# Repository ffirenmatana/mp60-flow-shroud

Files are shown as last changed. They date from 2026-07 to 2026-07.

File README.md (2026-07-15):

# MP60 low-profile 90° fan shroud (bottom-mounted VorTech)

A drop-in replacement for the EcoTech VorTech **MP60 wet-side cage** for
**through-the-bottom mounting** in a peninsula reef tank. Single 3D-printed
part: the stock bayonet mount and perforated intake barrel, plus a swept 90°
elbow that turns the vertical discharge into a wide, floor-angled ~90°-arc
sheet of flow aimed down the tank — a hideable gyre substitute for the open
end of a peninsula.

Total height **179 mm off the glass** (parametric). Geometry chosen by CFD:
a local optimization loop (lattice-Boltzmann sims + an LLM proposer) ran
dozens of 2D flow simulations, including full 1.8 m tank-scale runs with
rockwork, to pick every dimension. Details below.

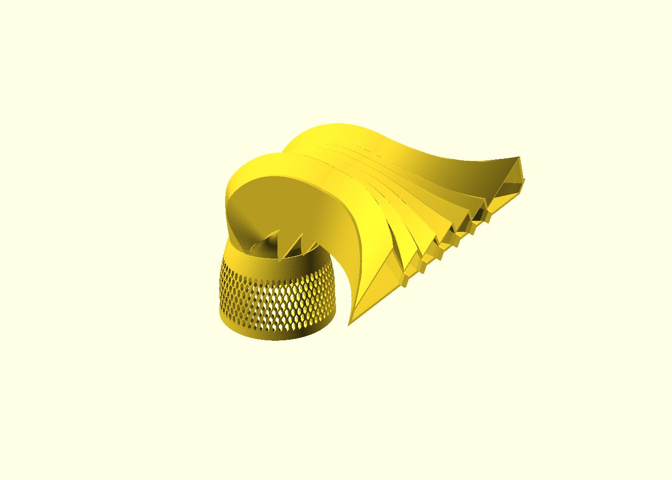
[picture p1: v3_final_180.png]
final part


## Design highlights (what the sims taught us)

| finding | detail |
|---|---|
| swept vaneless elbow | K ≈ 0.19 — turning vanes made it *worse* (0.61), mitered/louvered corners much worse (1.3–2.4). At this scale vane friction+wakes beat separation savings. |
| pump keeps ~97% flow | propeller-stall derating model: 5.35 of 5.52 L/s at 70% drive |
| fan needs vanes | without cambered splitter vanes the widening fan tunnels straight (spread σ20 mm); with 6 vanes it fills the full arc (σ57 mm) |
| 15° floor tilt | sweeps detritus off the bare bottom; 25° drives the sheet into the rockwork and dies |
| launch height rule | **the exit must clear the rock directly in front of it by 20–40 mm** — a below-crest exit dead-ends in a trapped vortex no matter the duct shape. This build: exit at 118 mm → keep foreground rock under ~93 mm |
| gothic-ridge roof | chevron cross-sections keep every interior surface ≥45°: single print, rim-down, supports only under the fan floor (build-plate) |

Tank-scale result vs a below-crest exit: coral-zone coverage 0 → 4.8%,
rock wrap-over 2.2×, dead zones behind rocks 100% → 73%.

## Files

- `mp60_shroud_v3.stl` — generated locally (325 cm³; 226×256×175 mm, fits Prusa Core One L 300×300×330), see below
- `build_v3.py` — fully parametric generator (numpy lofts + manifold
  booleans). Key knobs at top: `MAX_TOTAL_H_GLASS` (height cap, default
  180), `MAX_BED_XY` (build-plate cap, default 300), `WETSIDE_H`, wall, vanes. Reads `agent/final.json`.
- `cfd/lbm.py` — D2Q9 lattice-Boltzmann + Smagorinsky LES solver:
  elbow slice, fan plan, and closed-tank (with rocks, free surface,
  actuator jet) planes. Mass-balance-validated.
- `agent/` — the local optimization loop: qwen3:14b (Ollama) proposes
  candidates, this machine runs 8 parallel sims/round, tank sims decide
  finals. `agent/log.md` is the full campaign narrative.
- `cage.stl` — the stock cage mesh the part is built on (see attribution)

Earlier revisions (v1 OpenSCAD clamshell, v2 mitered-corner) are not in the
working tree; they live in git history if ever needed.

## Test the fit first (recommended)

Before the ~2-day full print, print the mount coupon — the bottom 22 mm
(bayonet + barrel), ~30 min, and twist it onto the wet side to confirm the
lock seats:

```bash
python3 make_coupon.py            # -> mp60_mount_coupon.stl
python3 make_coupon.py --pump mp40
```

The coupon is a boolean slice of the full part, so its mount geometry is
identical (verified 0.0000 mm vs the cage) — a good coupon fit means a good
part fit. Print it in the same PETG, no supports, no brim needed.

## MP40 variant

`build_v3.py --pump mp40` generates the same architecture scaled to the
MP40 cage (bore Ø56.9, three lugs at 120°, total ≈141 mm above the
glass). You need an MP40 wet-side cage mesh saved as `cage_mp40.stl`
(rim at z=0, axis up — the extractor's rotation applies; check the
license of whichever cage model you use before redistributing).

## Fidelity caveats

2D LES slices at reduced Reynolds number: excellent for *ranking*
geometries and flow topology (every decision here), indicative-only for
absolute velocities. The tank plane is a 2D vertical slice — real 3D
spread will be gentler. Not yet wet-tested; sim-driven design.

## Print & install

Slicer: PrusaSlicer, "Original Prusa Core One L" profile. Black PETG
(carbon black = UV stabiliser), 0.2 mm layers, 4 perimeters (walls are
3.2 mm = solid at 4), 15 % gyroid infill (part is mostly hollow duct).
Nozzle 245 °C, bed 85 °C, chamber passive/low (PETG doesn't want chamber
heat). Cooling fan ~30–40 % (bias to layer strength). Elephant-foot
compensation 0.15 mm (protects the bayonet-lug fit). Brim 5 mm.

Supports: **organic (tree), build-plate only, 45° threshold** — only the
fan underside needs them; the gothic roof self-supports. ~490 g PETG total.

Print the mount coupon first (`make_coupon.py`, ~30 min) to check the
bayonet before the full run.

Install: rinse, soak 24 h in saltwater, bayonet onto the wet side like the
stock cage, clock the fan down-tank before locking (lugs quantize to 120°
— fine-aim with the pump body). Bottom-mount basics: correct spacer for
your glass, catch bracket under the dry side, run 30–40 % for the first
week and listen to the bushing.

## Getting the STL (license-respecting build)

The intake cage geometry is ["Ecotech MP60 Cover" by asadler99 on
Cults3D](https://cults3d.com/en/3d-model/home/ecotech-mp60-cover), free
under the **Cults Private Use license** — which permits printing for
yourself but not redistribution of the mesh or derivatives. So this repo
does **not** contain `cage.stl` or the final shroud STLs; it contains
everything needed to build them locally in under a minute:

```bash
pip install numpy trimesh manifold3d scipy networkx
# download the free 3MF from the Cults link above, then:
python3 extract_cage.py ~/Downloads/EcotechV60Modified.3mf
python3 build_v3.py            # -> mp60_shroud_v3.stl
```

## Attribution & license

- Cage mesh: (c) [asadler99](https://cults3d.com/en/users/asadler99),
  [Cults PU license](https://cults3d.com/en/licenses#cults_pu) — print for
  private use only; not redistributed here. Thanks for a cleanly-modeled
  base part. (Permission to include the derived STLs has been requested
  from the author, July 2026 — if granted, prebuilt STLs will be added.) VorTech and MP60 are EcoTech Marine trademarks; this is an
  unaffiliated hobby project — use at your own risk.
- Code (generator, extractor, CFD solver, optimizer): MIT.

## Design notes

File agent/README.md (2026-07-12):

# Local optimization agent

Self-contained loop that perfects the MP60 shroud geometry using only
local hardware — no cloud tokens.

```
┌────────────────────┐    proposals+analysis   ┌───────────────────┐
│ M4 MacBook Pro     │ <────────────────────── │ M4 mini           │
│ optimizer.py       │                         │ Ollama qwen3:14b  │
│ 8x parallel LBM    │ ──────────────────────> │ 10.10.10.7:11434  │
│ sims per round     │    history JSON         └───────────────────┘
└────────────────────┘
```

## Run / resume / status

```bash
cd ~/Claude/Projects/MP60-flow-shroud/agent
../cfd-env-or-your-python optimizer.py          # runs or resumes
python3 optimizer.py --status                   # peek at state
tail -f log.md                                  # live narrative
```

State lives in `state.json`; kill and rerun anytime, it resumes.
`best.json` always holds the current winner → feed to `build_v3.py`.

## What a round does

1. qwen (mini) reads the scored history, proposes 4 candidates + a
   2-sentence analysis (logged). Fallback: local Gaussian/random proposer.
2. Each candidate → 2 sims on this Mac (elbow slice + fan plan),
   8 processes in parallel, 40k steps each.
3. Composite score = pump-derated exit momentum × arc coverage ×
   uniformity (see optimizer.py docstring for the MP60 stall model).
4. Plateau detection stops early; max 8 rounds.

## Tier B (the decider)

Top 3 aspect/tilt-distinct finalists get a 90k-step closed-tank sim:
1.8 m peninsula with rockwork (scape in front of the outlet, mid
bommie, near-wall structure), specular free surface, jet actuator at
the shroud exit angled down by the candidate's `tilt`.

Scored on: floor_sweep (detritus scouring), rock_wrap (climbing the
scape), lee_dead_frac (dead zones behind rocks), gyre_index +
wall_arrival (peninsula return loop). qwen renders the verdict;
a metric heuristic decides if it can't.

## Knobs

Env: `OPT_MAX_ROUNDS`, `OPT_N_PER_ROUND`, `OPT_SIM_STEPS`,
`OPT_TANK_STEPS`, `LOCAL_LLM_BASE`, `LOCAL_LLM_MODEL`.
Search space + physical constants at the top of optimizer.py.
Rock layout: `rocks` in `cfd/lbm.py::geom_tank` — edit to match the
real scape once it exists.

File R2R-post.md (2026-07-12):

# Reef2Reef draft — post in DIY / Members' 3D printing

**Title:** CFD-designed 3D-printed shroud turns a bottom-mounted MP60 into a
low-profile gyre for my peninsula — sim code + build recipe included

---

I have an acro-dominant peninsula and wanted serious flow at the open end
without hanging a gyre on the view panel. The plan: MP60 through the bottom
glass (bare bottom, dry side in the cabinet above the sump), with a printed
replacement for the wet-side cage that turns the vertical discharge 90° and
fans it into a wide sheet aimed back toward the wall end — hidden inside the
rockwork.

Instead of guessing the duct shape, I ended up going full nerd: a lattice-
Boltzmann CFD solver running locally, driven by an optimization loop (a local
LLM proposes candidate geometries, my machine simulates them — dozens of runs,
including full 1.8 m tank-scale sims with rockwork in them). A few results
that surprised me and might be useful to others:

- **Turning vanes made the elbow worse.** All the HVAC-style vane/louver
  designs lost badly to a plain swept bend (loss coefficient 0.19 vs 0.6–2.4).
  At powerhead scale, vane friction and wakes cost more than the separation
  they prevent.
- **The widening fan absolutely needs vanes though** — without them the flow
  tunnels straight out the middle instead of spreading into the 90° arc.
- **Where the exit sits beats how the duct is shaped.** If the outlet fires
  at rockwork taller than itself, the flow just churns in the gap and dies —
  every geometry, every time. The exit needs to clear the rock directly in
  front of it by a couple of cm. Sheet angled 15° at the floor then sweeps
  the sand and wraps over the scape; 25° just face-plants into the rock.
- The final part is 179 mm tall off the glass, keeps ~97% of the pump's flow
  (per a prop-stall derating model), prints in one piece in PETG with
  supports only under the fan, and bayonets onto the wet side exactly like
  the stock cage (the mount is the stock cage mesh from asadler99's free
  "Ecotech MP60 Cover" on Cults3D — its Private Use license means I can't
  redistribute the mesh, so the repo has a one-command script that rebuilds
  the STL from the 3MF you download from Cults yourself).

Fair warning: this is simulation-driven design, 2D slices with a turbulence
model — great for ranking shapes, not gospel for absolute numbers. It hasn't
been wet-tested yet; printing this week, will report back with PAR-meter…
sorry, flow-meter results and detritus observations.

Everything is on GitHub (the parametric generator, the CFD solver, the
whole optimization log): **https://github.com/ffirenmatana/mp60-flow-shroud**

Photos attached: the part, a cutaway of the internals, and the tank-scale
flow simulation showing the sheet wrapping over the scape.

*Suggested attachments:*
- `v3_final_180.png` (the part)
- `agent/runs/tank_hi_mid.png` (winning tank flow field)
- `agent/runs/tank_sheet_steep.png` (the "trench of doom" failure mode)
- `cfd/S5_swept_0v.png` (elbow flow field)

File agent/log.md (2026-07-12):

# MP60 shroud optimization log

seeded: [{"params": {"bend_r": 52, "duct_h": 45, "fan_len": 70, "exit_w": 185, "area_ratio": 1.19, "n_vanes": 4, "exp": 1.5}, "score": 0.3944, "metrics": {"K_loss": 0.20199999999999999, "Q_lps": 5.34, "v_exit": 1.114, "exit_h": 25.9, "spread": 45.7, "outfrac": 0.388, "plan_uni": 1.017}, "tag": "seed_S5_swept_0v"}]

## round 1  (18:46)
proposer: qwen. Candidates include variants near the historical best (bend_r=55, exit_w=200) and explore extremes like narrow exits (exit_w=120) and high tilt (30°). Prioritizes improving K and spread through parameter diversification.
8 sims in 15.5 min
- r1c0 {"bend_r": 55.0, "duct_h": 48.0, "fan_len": 75.0, "exit_w": 200.0, "area_ratio": 1.2, "n_vanes": 5, "exp": 1.6, "tilt": 10.0} -> score=0.293 {"K_loss": 0.19, "Q_lps": 5.35, "v_exit": 1.107, "exit_h": 24.2, "spread": 42.0, "outfrac": 0.236, "plan_uni": 1.294}
- r1c1 {"bend_r": 60.0, "duct_h": 50.0, "fan_len": 80.0, "exit_w": 260, "area_ratio": 1.4, "n_vanes": 6, "exp": 2.5, "tilt": 20.0} -> score=0.2945 {"K_loss": 0.17844444444444443, "Q_lps": 5.36, "v_exit": 0.951, "exit_h": 21.7, "spread": 62.9, "outfrac": 0.705, "plan_uni": 1.46}
- r1c2 {"bend_r": 45.0, "duct_h": 36, "fan_len": 55, "exit_w": 120, "area_ratio": 1.0, "n_vanes": 2, "exp": 1.2, "tilt": 0} -> score=0.2774 {"K_loss": 0.17, "Q_lps": 5.37, "v_exit": 1.333, "exit_h": 33.6, "spread": 22.1, "outfrac": 0.021, "plan_uni": 0.655}
- r1c3 {"bend_r": 65.0, "duct_h": 55.0, "fan_len": 100.0, "exit_w": 180.0, "area_ratio": 1.45, "n_vanes": 3, "exp": 2.0, "tilt": 15.0} -> score=0.1976 {"K_loss": 0.2555, "Q_lps": 5.3, "v_exit": 0.907, "exit_h": 32.4, "spread": 35.2, "outfrac": 0.144, "plan_uni": 1.212}
best so far: seed_S5_swept_0v score=0.3944

## round 2  (19:04)
proposer: qwen. Explored variants near the top-performing exit_w=185 with adjusted spread and tilt, while testing extreme exit_w=260 (sheet jet) and tilt=35 (floor-targeting) to explore uncharted regions.
8 sims in 15.2 min
- r2c0 {"bend_r": 52.0, "duct_h": 45.0, "fan_len": 70.0, "exit_w": 190.0, "area_ratio": 1.2, "n_vanes": 4, "exp": 1.6, "tilt": 5.0} -> score=0.3565 {"K_loss": 0.22061111111111112, "Q_lps": 5.32, "v_exit": 1.102, "exit_h": 25.4, "spread": 43.5, "outfrac": 0.31, "plan_uni": 1.054}
- r2c1 {"bend_r": 50.0, "duct_h": 44.0, "fan_len": 65.0, "exit_w": 180.0, "area_ratio": 1.15, "n_vanes": 4, "exp": 1.4, "tilt": 0} -> score=0.4189 {"K_loss": 0.146, "Q_lps": 5.39, "v_exit": 1.163, "exit_h": 25.7, "spread": 45.8, "outfrac": 0.457, "plan_uni": 0.993}
- r2c2 {"bend_r": 60.0, "duct_h": 50.0, "fan_len": 80.0, "exit_w": 260, "area_ratio": 1.4, "n_vanes": 6, "exp": 2.5, "tilt": 20.0} -> score=0.2945 {"K_loss": 0.17844444444444443, "Q_lps": 5.36, "v_exit": 0.951, "exit_h": 21.7, "spread": 62.9, "outfrac": 0.705, "plan_uni": 1.46}
- r2c3 {"bend_r": 44, "duct_h": 36, "fan_len": 55, "exit_w": 120, "area_ratio": 1.0, "n_vanes": 2, "exp": 1.2, "tilt": 35} -> score=0.2716 {"K_loss": 0.2361111111111111, "Q_lps": 5.31, "v_exit": 1.319, "exit_h": 33.6, "spread": 22.1, "outfrac": 0.021, "plan_uni": 0.655}
best so far: r2c1 score=0.4189

## round 3  (19:22)
proposer: qwen. The best historical candidate (score 0.4189) is near the lower bend_r/duct_h range with moderate exit_w. Exploration candidates test higher exit_w (gyre-like sheet), increased tilt (detritus sweeping), and extreme area_ratio/n_vanes combinations. The fourth candidate probes unexplored low-bend_r/duct_h territory with balanced parameters.
8 sims in 14.1 min
- r3c0 {"bend_r": 50.0, "duct_h": 44.0, "fan_len": 65.0, "exit_w": 180.0, "area_ratio": 1.15, "n_vanes": 4, "exp": 1.4, "tilt": 0} -> score=0.4189 {"K_loss": 0.146, "Q_lps": 5.39, "v_exit": 1.163, "exit_h": 25.7, "spread": 45.8, "outfrac": 0.457, "plan_uni": 0.993}
- r3c1 {"bend_r": 55.0, "duct_h": 48.0, "fan_len": 75.0, "exit_w": 220.0, "area_ratio": 1.3, "n_vanes": 5, "exp": 1.8, "tilt": 15.0} -> score=0.2433 {"K_loss": 0.1995, "Q_lps": 5.34, "v_exit": 1.02, "exit_h": 23.8, "spread": 42.1, "outfrac": 0.196, "plan_uni": 1.414}
- r3c2 {"bend_r": 65.0, "duct_h": 55.0, "fan_len": 100.0, "exit_w": 150.0, "area_ratio": 1.45, "n_vanes": 3, "exp": 2.2, "tilt": 25.0} -> score=0.1854 {"K_loss": 0.2798333333333333, "Q_lps": 5.28, "v_exit": 0.904, "exit_h": 38.9, "spread": 28.8, "outfrac": 0.075, "plan_uni": 0.924}
- r3c3 {"bend_r": 48.0, "duct_h": 40.0, "fan_len": 80.0, "exit_w": 200.0, "area_ratio": 1.25, "n_vanes": 6, "exp": 2.0, "tilt": 10.0} -> score=0.348 {"K_loss": 0.2677777777777778, "Q_lps": 5.29, "v_exit": 1.05, "exit_h": 25.2, "spread": 52.8, "outfrac": 0.501, "plan_uni": 1.189}
best so far: r2c1 score=0.4189

## round 4  (19:37)
proposer: qwen. Top candidates cluster near the best historical score (0.4189) with slight parameter adjustments. Unexplored regions include low-exit_w (130) and high-tilt (30), testing detritus-sweeping potential. Area_ratio and exp variations aim to balance jet coherence (exp=1.3-2.4) with flow spread (spread=22-63).
8 sims in 15.4 min
- r4c0 {"bend_r": 52.0, "duct_h": 46.0, "fan_len": 68.0, "exit_w": 185.0, "area_ratio": 1.18, "n_vanes": 4, "exp": 1.5, "tilt": 2.0} -> score=0.3508 {"K_loss": 0.16355555555555557, "Q_lps": 5.37, "v_exit": 1.131, "exit_h": 25.7, "spread": 39.9, "outfrac": 0.296, "plan_uni": 1.03}
- r4c1 {"bend_r": 58.0, "duct_h": 48.0, "fan_len": 72.0, "exit_w": 190.0, "area_ratio": 1.22, "n_vanes": 5, "exp": 1.6, "tilt": 10.0} -> score=0.2413 {"K_loss": 0.1811111111111111, "Q_lps": 5.36, "v_exit": 1.091, "exit_h": 25.9, "spread": 37.4, "outfrac": 0.142, "plan_uni": 1.238}
- r4c2 {"bend_r": 46.0, "duct_h": 38.0, "fan_len": 60.0, "exit_w": 130.0, "area_ratio": 1.05, "n_vanes": 3, "exp": 1.3, "tilt": 30.0} -> score=0.2484 {"K_loss": 0.2293333333333333, "Q_lps": 5.32, "v_exit": 1.258, "exit_h": 32.5, "spread": 23.3, "outfrac": 0.025, "plan_uni": 0.791}
- r4c3 {"bend_r": 62.0, "duct_h": 52.0, "fan_len": 90.0, "exit_w": 250.0, "area_ratio": 1.4, "n_vanes": 6, "exp": 2.4, "tilt": 25.0} -> score=0.3017 {"K_loss": 0.1878333333333333, "Q_lps": 5.35, "v_exit": 0.949, "exit_h": 22.5, "spread": 56.6, "outfrac": 0.622, "plan_uni": 1.368}
best so far: r2c1 score=0.4189
plateau -> stopping tier A early

## tier B: tank-scale gyre sims
- tank_sheet_shallow: r2c1 exit 180.0x26mm v_exit=1.163m/s
- tank_sheet_steep: r4c3 exit 250.0x23mm v_exit=0.949m/s
- tank_diffuse_shallow: r1c2 exit 120x34mm v_exit=1.333m/s
- tank_sheet_shallow -> {"coral_mean_u": 0.0012, "coral_frac_gt_10pct": 0.0, "coral_frac_gt_25pct": 0.0, "wall_arrival_u": 0.0, "gyre_index": 0.0157, "floor_sweep_u": 0.0485, "rock_wrap_u": 0.0691, "lee_dead_frac": 1.0, "tank_mean_u": 0.0946, "name": "tank_sheet_shallow"}
- tank_sheet_steep -> {"coral_mean_u": 0.0026, "coral_frac_gt_10pct": 0.0, "coral_frac_gt_25pct": 0.0, "wall_arrival_u": 0.0001, "gyre_index": 0.0071, "floor_sweep_u": 0.071, "rock_wrap_u": 0.0719, "lee_dead_frac": 1.0, "tank_mean_u": 0.0782, "name": "tank_sheet_steep"}
- tank_diffuse_shallow -> {"coral_mean_u": 0.0052, "coral_frac_gt_10pct": 0.0, "coral_frac_gt_25pct": 0.0, "wall_arrival_u": 0.0001, "gyre_index": -0.0014, "floor_sweep_u": 0.0363, "rock_wrap_u": 0.0984, "lee_dead_frac": 0.995, "tank_mean_u": 0.1117, "name": "tank_diffuse_shallow"}

## VERDICT: {"winner": "sheet_steep", "why": "sheet_steep has the highest floor_sweep_u (0.071), meeting the first goal. While its rock_wrap_u (0.0719) is moderate and lee_dead_frac (1.0) is high, it's the best among options for the first priority. Gyre_index and wall_arrival_u are lower than sheet_shallow, but secondary goals are less critical."}

DONE. best.json written -- feed to build_v3.py

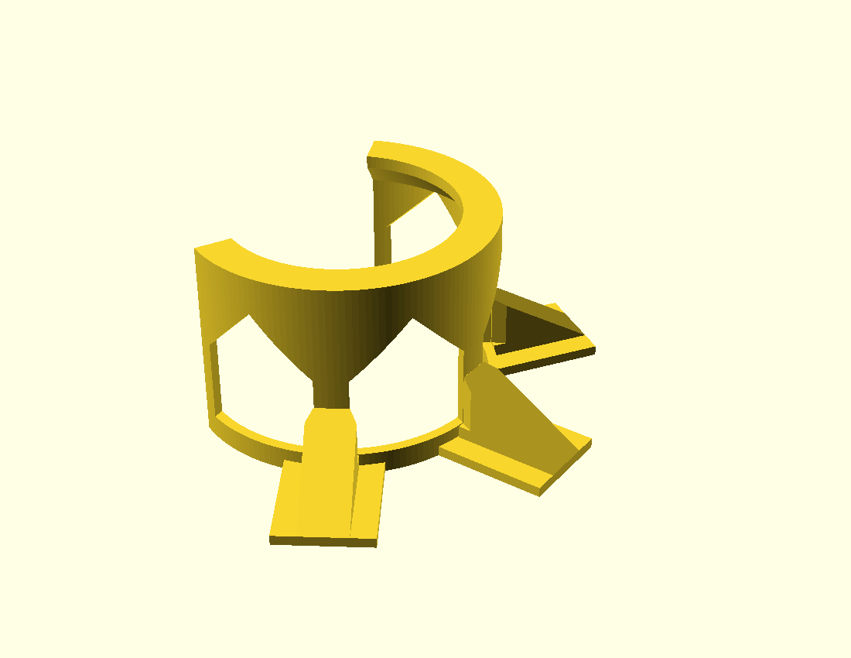
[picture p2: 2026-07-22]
bracket_view1.png

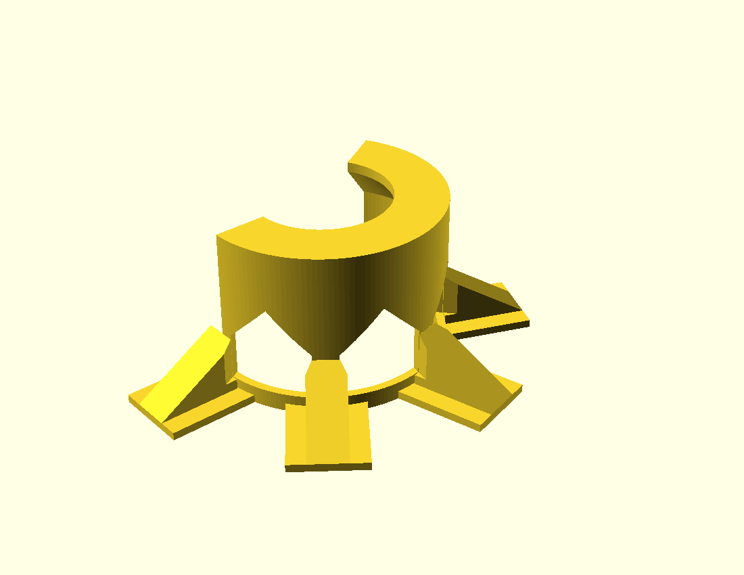
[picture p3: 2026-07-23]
bracket_v3.png

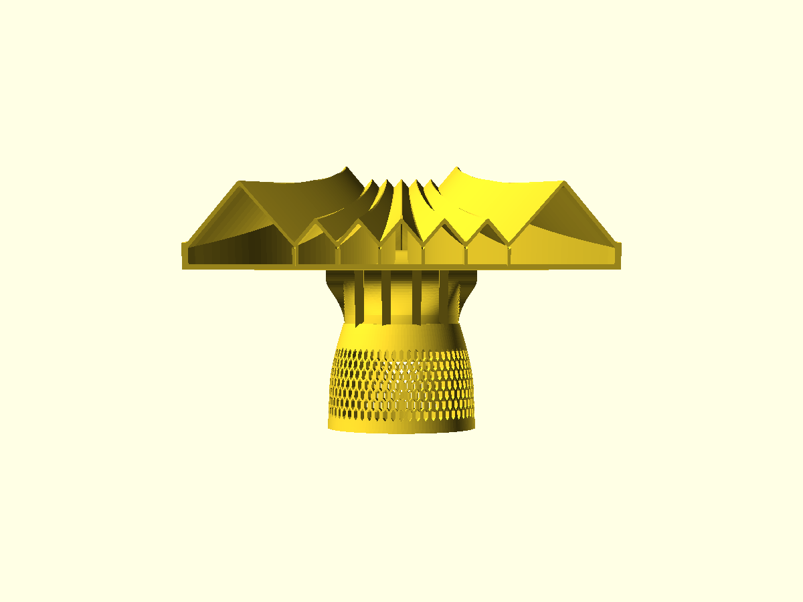
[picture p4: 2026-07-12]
v3_final2.png

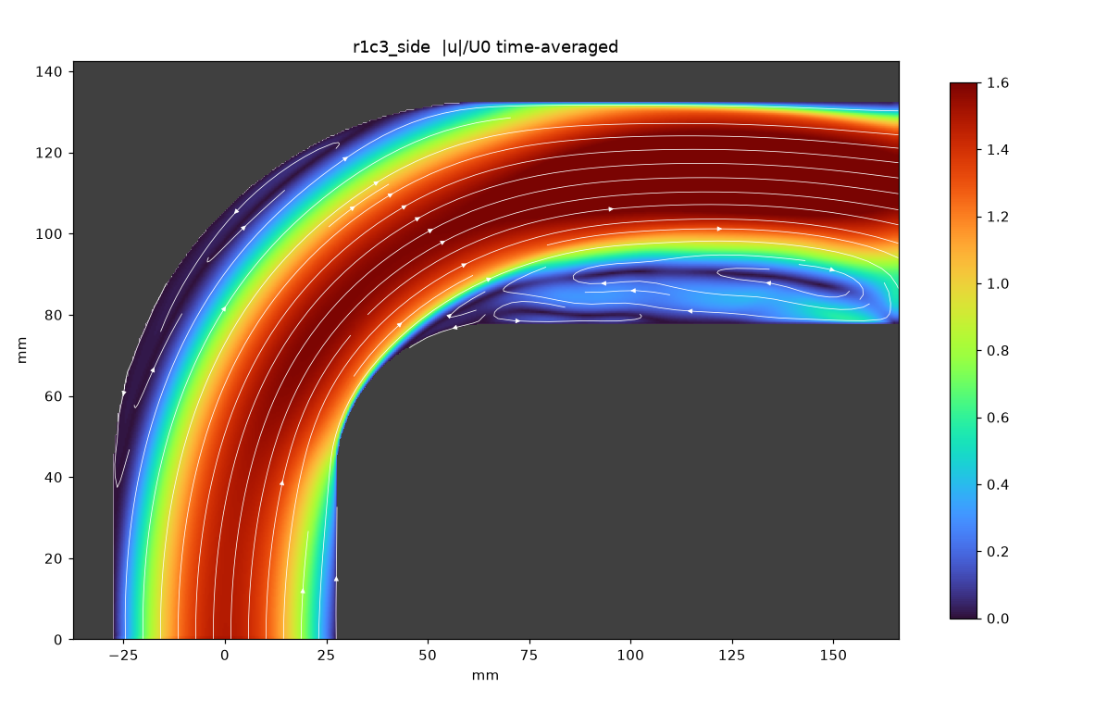
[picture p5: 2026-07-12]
agent/runs/r1c3_side.png

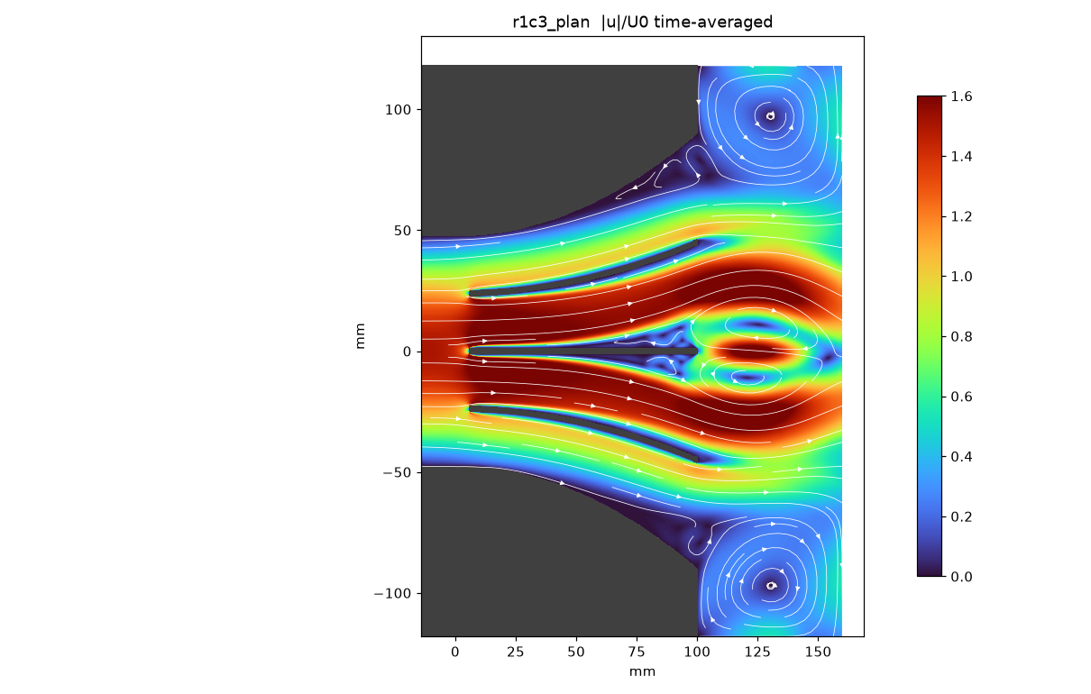
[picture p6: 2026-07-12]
agent/runs/r1c3_plan.png

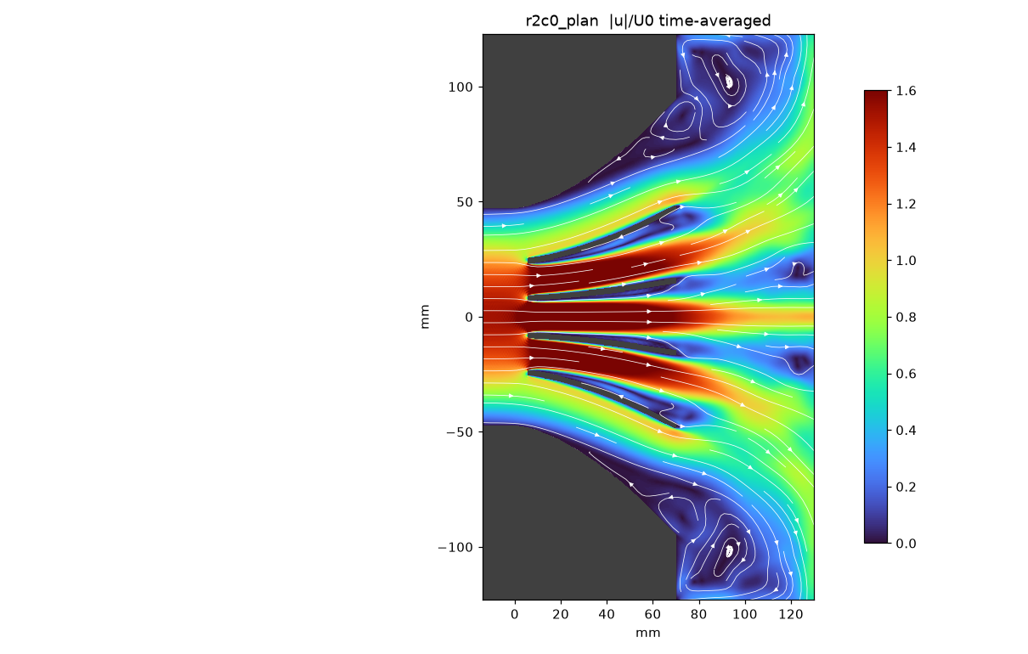
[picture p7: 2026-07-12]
agent/runs/r2c0_plan.png

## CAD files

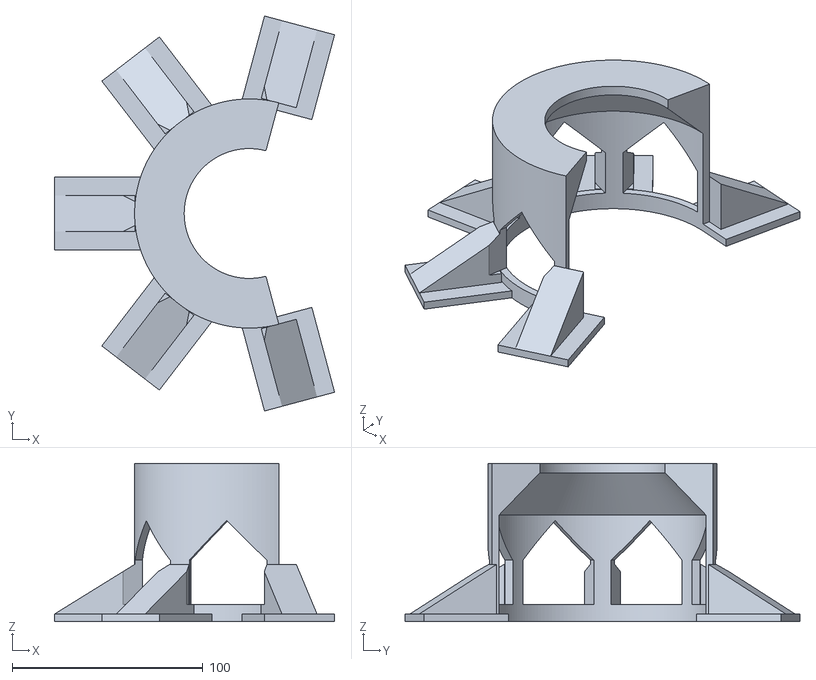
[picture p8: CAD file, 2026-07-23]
dryside_bracket.stl
146.8 x 206.9 x 83.0

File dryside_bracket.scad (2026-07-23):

// ============================================================
// MP60 dry-side catch bracket ("safety basket") -- v2, arched windows
//
// Glues to the UNDERSIDE of the tank's bottom glass with 20kg
// double-sided tape. Job: if the magnetic coupling ever releases,
// the dry side drops 3mm onto the ledge instead of into the sump.
//
// Design rules:
//  * NEVER touches the dry side in normal operation (2.5mm radial
//    clearance past the rubber shim): zero vibration coupling, the
//    magnetic seating and shim do their job undisturbed.
//  * Venting: 4 big gothic-arched windows + the open mouth expose
//    most of the air-cooled housing. Arched tops = self-supporting.
//  * C-shape, 150 deg mouth: dry side slides out sideways for
//    service without peeling the tape. INSTALL with the mouth
//    pointing the SAME direction as the fan exit (thrust reaction
//    pushes the pump into the closed back of the C).
//  * Print PADS-DOWN on the textured sheet: tape face comes out
//    dead flat. No supports needed anywhere.
//
// MEASURE FIRST (calliper the dry side):
DRY_OD     = 100;  // MEASURED 2026-07-13 (magnet makes it fiddly; clearance absorbs +/-1mm)
DRY_H      = 73;   // MEASURED (if this excluded the ~2mm shim face,
                   // the 5mm drop gap below still leaves 3mm clearance)
SHIM_EXTRA = 4;    // MEASURED: 2mm shim wall -> +4mm on diameter
// ------------------------------------------------------------
CLEAR     = 4.0;   // radial clearance past the shim -- ZERO contact
                   // required; widened after v2 measured ~2mm
DROP_GAP  = 5;     // ledge below the dry side; sized to absorb the
                   // shim-thickness ambiguity in DRY_H
WALL      = 4;
LEDGE_W   = 22;    // deep ledge + 45deg self-centering funnel.
                   // MEASURED housing profile (2026-07-23, hanging from
                   // glass): O100 shim face -> O95 above cable entry ->
                   // O78 at the vent shelf -> O62 at the logo face (that
                   // last step over only 5mm). Catch mechanics: the O78
                   // vent shelf seats on the funnel after a ~5mm drop
                   // (housing bottom cone is steeper than the 45deg
                   // funnel, so the wide rim contacts first); the O62
                   // tip hovers inside the 68mm opening. >=5mm running
                   // clearance at every depth. Route the power cord out
                   // through the MOUTH -- pinned between housing and
                   // shell it would bridge vibration.
LEDGE_T   = 5;
PAD_L     = 42;    // tape pad, radial
PAD_W     = 38;    // tape pad, tangential
TOP_BAND  = 9;     // solid band at the tape plane
MOUTH_DEG = 150;   // v3: widened again for easy service removal
                   // (chord ~108mm vs the 100mm housing)

ID     = DRY_OD + SHIM_EXTRA + 2*CLEAR;
R_IN   = ID/2;
R_OUT  = R_IN + WALL;
H_COL  = DRY_H + DROP_GAP;         // tape plane -> catch face
H_TOT  = H_COL + LEDGE_T;
C_A0   = MOUTH_DEG/2;              // C spans C_A0 .. 360-C_A0, mouth on +X
C_SPAN = 360 - MOUTH_DEG;
RIBS   = [for (i = [0:4]) C_A0 + i*C_SPAN/4];   // 5 rib centers
PADS   = RIBS;   // v3: pads on ALL five ribs -- the two mouth-shoulder
                 // feet stop catch loads levering/peeling the back pads
WIN_H0 = TOP_BAND;                 // window bottom (print z)
WIN_H1 = H_COL - LEDGE_W - 3;      // window apex: MUST end 3mm below the
                                   // chamfer start so the ledge cone always
                                   // begins on a full solid ring (v2's arch
                                   // peaks poked above it -> mid-air chamfer
                                   // start over windows -> the print failure)
$fn = 160;

module c_shell() {
    rotate([0, 0, C_A0]) rotate_extrude(angle = C_SPAN)
        translate([R_IN, 0]) square([WALL, H_TOT]);
}

module ledge() {
    // catch ring + 45deg chamfer, both riding on the full shell
    rotate([0, 0, C_A0]) rotate_extrude(angle = C_SPAN) union() {
        translate([R_IN - LEDGE_W, H_COL]) square([WALL + LEDGE_W, LEDGE_T]);
        polygon([[R_IN, H_COL], [R_IN - LEDGE_W, H_COL],
                 [R_IN, H_COL - LEDGE_W]]);
    }
}

module window_cutter(ang) {
    // chordal prism with a 45deg pointed-arch top, pushed through the wall
    win_w = 2 * R_IN * sin((C_SPAN/4 - 9)/2);      // leaves ~9deg ribs
    rise  = min(win_w/2, WIN_H1 - WIN_H0 - 10);
    rotate([0, 0, ang]) translate([(R_IN + R_OUT)/2, 0, 0])
        rotate([90, 0, 90]) translate([0, 0, -WALL*2]) linear_extrude(WALL*4)
            polygon([[-win_w/2, WIN_H0], [win_w/2, WIN_H0],
                     [win_w/2, WIN_H1 - rise], [0, WIN_H1],
                     [-win_w/2, WIN_H1 - rise]]);
}

module pad(ang) {
    rotate([0, 0, ang]) {
        translate([R_IN, -PAD_W/2, 0]) cube([WALL + PAD_L, PAD_W, WALL]);
        hull() {   // 45deg gusset, prints pads-down with no support
            translate([R_OUT - 0.1, -PAD_W/4, 0])
                cube([0.1, PAD_W/2, WALL + 26]);
            translate([R_OUT + PAD_L - 8, -PAD_W/4, 0])
                cube([8, PAD_W/2, WALL]);
        }
    }
}

difference() {
    union() {
        c_shell();
        ledge();
        for (a = PADS) pad(a);
    }
    for (i = [0:3]) window_cutter(C_A0 + (i + 0.5) * C_SPAN/4);
}

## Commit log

2026-07-12 MP60 bottom-mount fan shroud: CFD-optimized cage replacement
    Swept vaneless elbow + vaned fan, 15 deg floor tilt, 179mm total height.
    Geometry selected by local LBM/qwen optimization loop (agent/); campaign
    log in agent/log.md. Cage mesh (c) asadler99 (Cults PU) is NOT included:
    extract_cage.py + build_v3.py regenerate the STL locally from the free
    3MF -- see README.
    [half_A.stl, half_B.stl, mp60_fan_shroud.scad]
2026-07-12 Corbel: solid web -> 4x 6mm ribbed gussets at 55 deg
    Same load path (fan-root shear into the riser tube -- the old web's outer
    corners had no anchor and did little), ~1/5 the visual bulk, 22mm less
    reach, 76cm3 lighter. Bays between ribs bridge at 12-18mm.
2026-07-12 Fix chiral mount bug (rotation, not reflection); add MP40 variant
    extract_cage.py used an axis swap (det=-1) so cage.stl and every STL
    built from it was MIRRORED -- the bayonet lugs are chiral (up to 3.7mm
    directional geometry in the mount band), a mirrored part will not
    twist-lock. Now a proper rotation; both pumps' mount bands verify at
    0.0000mm against their sources.
    build_v3.py --pump mp40: same architecture at 0.795x (bore 56.9), 141mm
    total height. MP40 cage mesh not redistributed (user-supplied STL,
    unknown license) -- gitignored like the MP60 meshes.
2026-07-12 Clean up: remove superseded v1/v2 revisions and scratch artifacts
    Working tree now holds only the current v3 deliverables (MP60 + MP40) and
    what regenerates them. Removed:
    - v1 OpenSCAD clamshell (mp60_fan_shroud.scad, half_A/B.stl, scratch renders)
    - v2 mitered-corner design (build_v2.py, v2 STLs + renders) -- lost the CFD
    - v3 debug intermediates (shell/corbel/vanes STLs, corbel comparison renders)
    All recoverable from git history.
    [half_A.stl, half_B.stl, mp60_fan_shroud.scad]
2026-07-12 Add mount-coupon generator for pre-print fit test
    make_coupon.py slices the bottom 22mm (bayonet + barrel) off the full part
    for a ~30-min fit-test print before committing to the full run. Mount
    geometry verified 0.0000mm vs cage; manifold=yes. Coupon STLs gitignored
    (derived from licensed cage).
2026-07-13 Add MAX_BED_XY build-plate cap; fit MP60 to 270mm bed
    Fan width (exit_w) capped 250->230 so the Y footprint drops 256->236mm,
    leaving 34mm for a brim. Mount frozen (0.0000mm vs cage). EXIT_AREA is
    set by area_ratio, so the narrower exit just gets taller (230x24.5 vs
    250x22.5) -- pump K and flow delivery unchanged, marginally less arc.
2026-07-15 Revert to full-size exit (Core One L 300x300x330 bed)
    MAX_BED_XY 270->300 so exit_w stays at the optimizer's 250mm winner;
    footprint 226x256x175 fits with 44mm+ margin. Mount unchanged (0.0000mm).
2026-07-15 README: Core One L print settings (PrusaSlicer, organic supports)
2026-07-22 Dry-side catch bracket: vented C-cradle, tape-mounted
    Safety net for the bottom-mounted dry side: 3mm drop gap onto a C-ledge
    (never touches the housing -- preserves shim vibration isolation and
    magnetic seating), 130deg service mouth, gothic-arched vent windows,
    ~5000mm2 coplanar tape face. Prints pads-down, no supports. Original
    geometry (no licensed mesh) so the STL ships in-repo.
    [dryside_bracket.scad, dryside_bracket.stl]
2026-07-22 Bracket: measured dims (OD 100, H 73, shim +4), mouth 130->140
    Narrower basket shrank the mouth chord below the housing OD; widened so
    sideways service removal still works (chord 102.4 vs 100).
    [dryside_bracket.scad, dryside_bracket.stl]
2026-07-22 Bracket: drop gap 3->5mm, robust to shim-thickness ambiguity in DRY_H
    [dryside_bracket.scad, dryside_bracket.stl]
2026-07-23 Bracket v3: fix print failure root cause + tapered-housing catch
    v2 failed in print: the ledge chamfer ring started above the window arch
    peaks, so over each window its first layers launched from mid-air.
    Windows now end 3mm below the chamfer (verified continuous solid ring at
    the cone start). Owner's fit check also exposed that the dry side TAPERS
    (~100 -> ~78mm): v2's 87mm ledge opening could have let the housing fall
    straight through. v3: 22mm deep ledge, 68mm opening, 45deg cone doubles
    as a self-centering catch funnel. Also per owner: clearance 2.5 -> 4mm
    (zero-contact), mouth 140 -> 150deg (service removal), pads on all five
    ribs (mouth-shoulder feet stop lever/peel).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
    [dryside_bracket.scad, dryside_bracket.stl]
2026-07-23 Bracket: document measured dry-side taper + catch mechanics
    O100->95->78->62 profile; O78 vent shelf seats on the funnel after ~5mm
    drop, tip hovers in the opening, >=5mm running clearance throughout.
    No geometry change needed. Cord routes out the mouth.
    [dryside_bracket.scad]
